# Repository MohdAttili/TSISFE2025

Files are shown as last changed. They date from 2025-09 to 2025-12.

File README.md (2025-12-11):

## WRO-FUTURE-ENGINEERS-2025 - TEAM TUREAH

<p align="center">
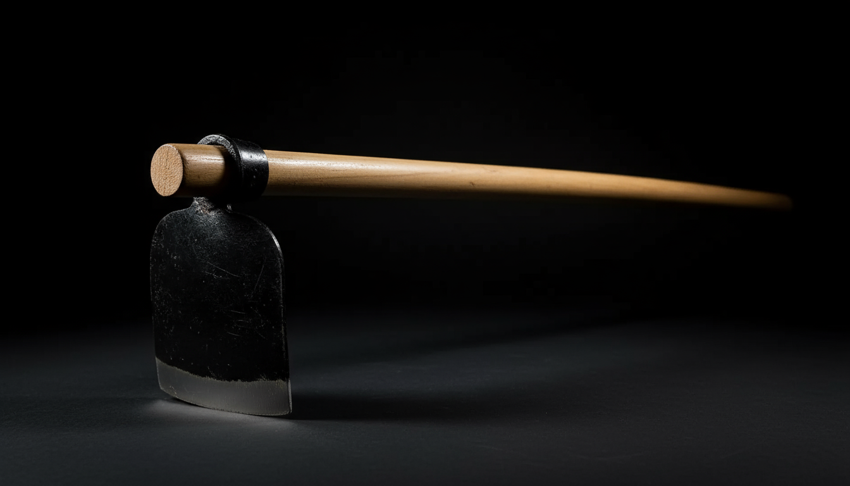
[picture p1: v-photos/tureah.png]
Team Photo

</p>

---

## Vehicle Preview
<p align="center">
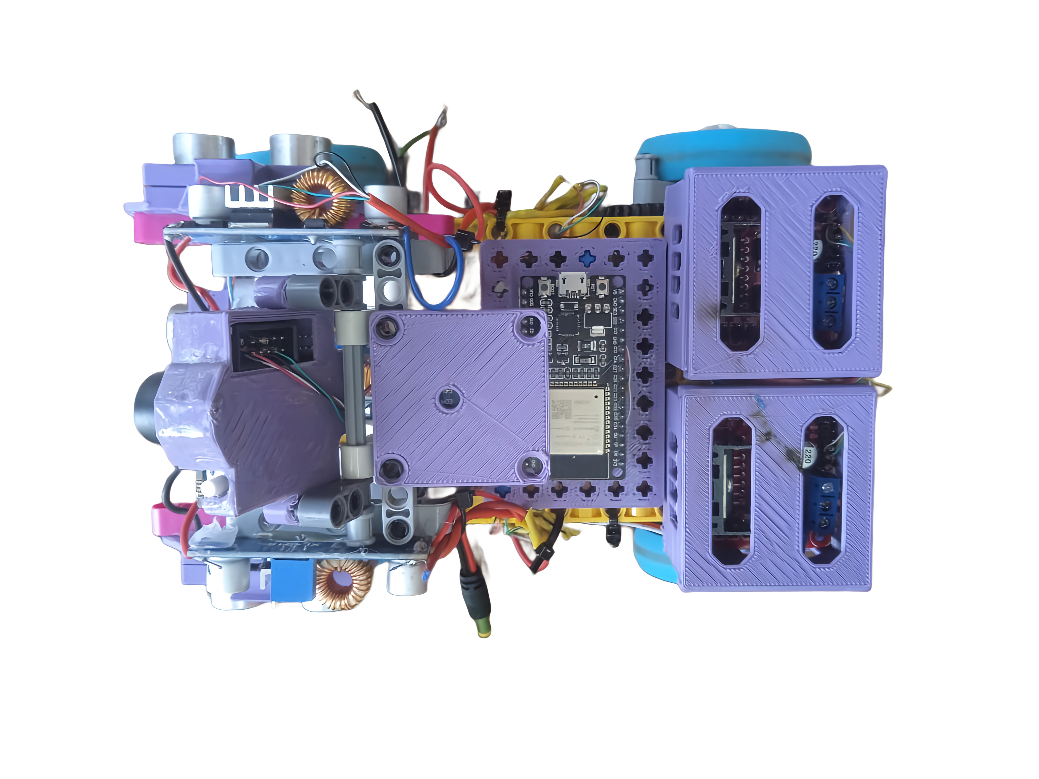
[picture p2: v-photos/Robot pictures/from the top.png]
Vehicle Photo

</p>

---
An autonomous vehicle designed for the Future Engineers category of the WRO 2025 that uses computer vision and IMU sensors to navigate complex environments and avoid obstacles intelligently.

## Content Structure

📁 **t-photos** → [team photos ](https://github.com/MohdAttili/TSISFE2025/tree/main/t-photos)   
📁 **v-photos** → [vehicle photos  ](https://github.com/MohdAttili/TSISFE2025/tree/main/v-photos)   
📁 **video** → [video.md with demonstration link  ](https://github.com/MohdAttili/TSISFE2025/tree/main/video)   
📁 **schemes** → [schematic diagrams ](https://github.com/MohdAttili/TSISFE2025/tree/main/schemes)    
📁 **src** → [control software  ](https://github.com/MohdAttili/TSISFE2025/tree/main/src)   
📁 **models** → [3D printing / laser cutting / CNC files ](https://github.com/MohdAttili/TSISFE2025/tree/main/models)    
📁 **other** → [documentation and additional resources  ](https://github.com/MohdAttili/TSISFE2025/tree/main/other)   
## Project Overview
This repository contains all the engineering materials, code, schematics, and models related to our self-driven vehicle, designed and built to participate in the WRO Future Engineers 2025 competition. The project aims to develop an autonomous vehicle capable of navigating a predefined course while demonstrating precision, stability, and effective control of electromechanical components.

Our vehicle is a compact, versatile model incorporating both mechanical and electronic systems. It is designed to efficiently demonstrate autonomous navigation using sensors, motor control, and a central microcontroller. The design and implementation of this project involved detailed planning, testing, and iterative improvements to meet the strict requirements of the competition.
## -------------------------------------------------------------------------------------
## Why TUREAH

**Our team is called "TUREAH" after the farming tool, symbolizing hard work, perseverance, and the ability to overcome obstacles. Just like the tool prepares the soil for growth, our team paves the way for success. 🌱**
## -------------------------------------------------------------------------------------

## Who We Are

<!-- <p align="center">
<img src="t-photos/karem1.jpg" alt="Kareem" width="240"height="250" />
<img src="t-photos/attili.jpg" alt="Attili" width="240"/>
<img src="t-photos/osama1.jpeg" alt="Osama" width=240/>
</p> -->

<table border="1">
  <tr>
    <td align="center">
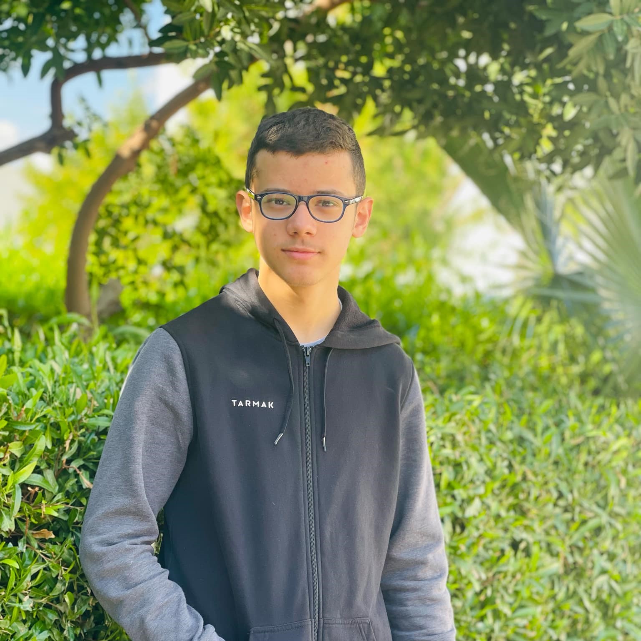
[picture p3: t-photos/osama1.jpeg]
      <br>
      Osama Jadbah<br>
      Planning <br>
      Research<br>
      Documentation
    </td>
    <td align="center">
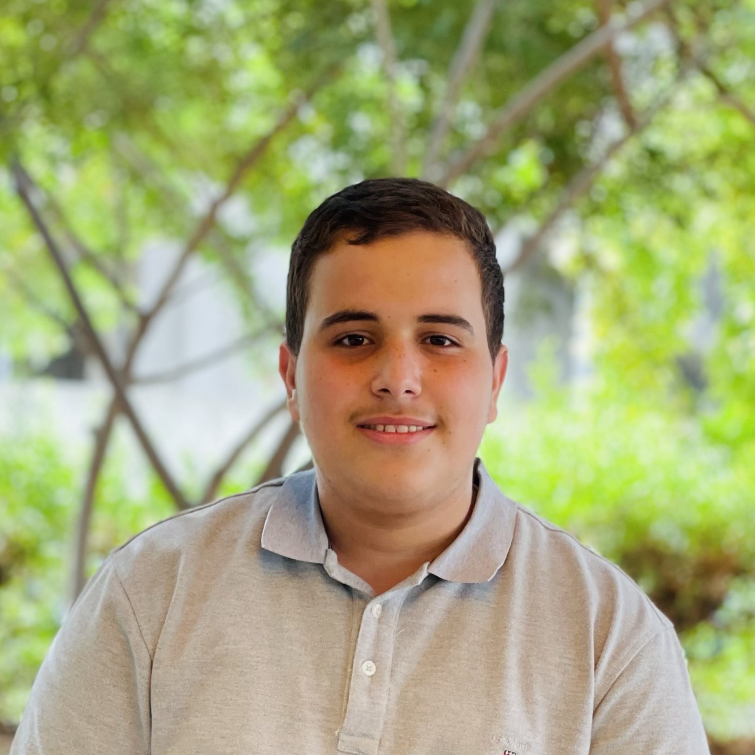
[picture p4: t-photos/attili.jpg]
      <br>
      Mohammad Attili<br>
      Hardware <br>
      Software
    </td>
    <td align="center">
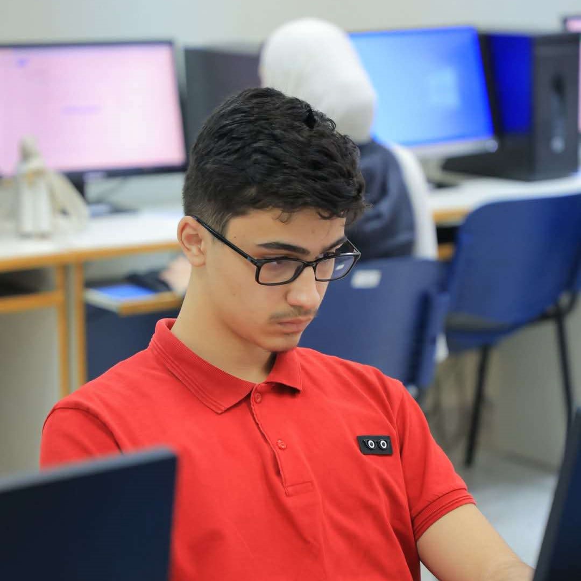
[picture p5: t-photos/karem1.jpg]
      <br>
      Kareem Amr<br>
      Mechanical Design<br>
      Algorithms
    </td>    
  </tr>
</table>

We are a team of three passionate Palestinian students from Tulkarm Industrial Secondary School, united by our love for programming, artificial intelligence, and problem-solving. Osama Jadbah, an 11th-grade student, focuses on lifelong learning, self-development, and has earned multiple excellence certificates for his achievements. Mohammad Attili, 16, is a competitive programmer who has excelled in national and international contests, showcasing his innovation and tech skills. Kareem Amr, also 16, is a skilled programmer and problem solver, experienced in algorithms and competitive programming, and an accomplished chess player who earned 3rd place in the Palestinian Chess Championship. Together, we strive to develop our skills, tackle challenging projects, and explore new technological horizons.
[Further Information](https://github.com/MohdAttili/TSISFE2025/blob/main/t-photos/Team%20Description.pdf)
## -------------------------------------------------------------------------------------
## 🔍 Project Description
**🎯 Goals**  
1. Build a functional self-driven vehicle that can navigate a course autonomously.  
2. Integrate electronic and mechanical components seamlessly.  
3. Develop modular and maintainable code to control all vehicle components.  
4. Document all aspects of the vehicle's design, construction, and programming.  
5. Provide clear and detailed engineering materials to facilitate understanding and replication.  

 ## ⚙️ Physical Equipment  
**1. 🧠 ESP32-WROOM-32 Overview**
1. ESP32-WROOM-32 is a microcontroller by Espressif with Wi-Fi and Bluetooth, commonly used in smart devices and robotics.
2. It features a dual-core Xtensa 32-bit LX6 processor up to 240 MHz, with 520 KB SRAM and 4 MB Flash.
3. Offers around 34 programmable GPIO pins and interfaces like SPI, I2C,  UART, PWM, and I2S, with ADC/DAC support.  
4. Supports dual connectivity, multiple protocols, and has a large  community with ready-to-use libraries.  
5. Common applications include robotics, smart home systems, remote   measurement/control devices, and IoT data collection.  
                    
**2. 🤖 L298N (Motor Driver Module) Overview**
1. The L298N is a dual H-bridge motor driver used to control the speed and direction of DC and stepper motors.
2. Supports motor voltages from 5V to 35V and currents up to 2A per channel.
3. Motor direction is controlled via IN1–IN4 pins and speed via PWM (ENA/ENB pins).
4. Features include independent dual motor control, built-in heat sink, and easy interfacing with Arduino, ESP32, and Raspberry Pi.
5. Commonly used in robotics, motorized DIY projects, and stepper motor control for small CNC machines or 3D printers.

**3. 📏 HC-SR04 Ultrasonic Sensor Overview**     
1. Ultrasonic distance sensor used to measure distances to objects.
2. Sends ultrasonic waves and calculates the time for echo return.
3. Affordable, simple, and widely used in robotics and obstacle detection.
4. Features a simple 4-pin interface: VCC, GND, TRIG, ECHO.
5. Provides accurate distance measurement (2 cm – 400 cm, ±3 mm).
     
**4.🎥 Pixy 2.1 (CMUcam5) Overview**
1. The Pixy 2.1 is a smart vision sensor that detects and tracks objects by color or shape.
2. Resolution: 320×200 pixels, frame rate up to 60 fps, with interfaces SPI, I²C, UART, and USB.
3. Built-in processor allows real-time object recognition and can track multiple objects simultaneously.
4. Sends object coordinates directly to microcontrollers like Arduino or ESP32, reducing main board load.
5. Common applications include line-following robots, object detection/sorting, interactive projects, and educational AI experiments.

**5. 🚗 LEGO Wheel Ø56 with Medium Azure Tire Overview**
1. LEGO Technic wheel with a 56 mm diameter and medium azure rubber tire.
2. Part numbers: 39367 (wheel) and 1282073 (tire).
3. Designed for medium-sized LEGO vehicles and robots.
4. Durable and easy to fit with LEGO axles, providing reliable traction.
5. Common uses: LEGO Mindstorms robots, Spike Prime projects, and DIY educational builds.

**6. ⚡ MG996R Servo Overview**
1. High-torque digital servo with reliable performance and precise positioning.   
2. Operating Voltage: 4.8–6.0V DC, providing ~9.4–11 kg·cm torque.     
3. Applications: Suitable for steering, robotic arms, and hobby projects.   
4. Motor & Gears: Coreless motor with durable metal gears for smooth, accurate motion.   
4. Control & Integration: Controlled via standard PWM; compatible with Arduino, Raspberry Pi, and robotics kits.   

**7. ⚙️ EV3 Medium Motor Overview**
1. A LEGO Mindstorms motor designed for precise and controlled movement.
2. Operates at ~255 RPM with medium torque, ideal for steering mechanisms.
3. Features a built-in rotation sensor for accurate position feedback.
4. Supports precise angle control (servo-like behavior) and smooth acceleration.
5. Commonly used in LEGO Technic robots for steering and articulated parts.
      
**8. 🧩 EV3 LEGO Technic Set Pieces Overview**
1. Modular LEGO Technic parts used to build robots, vehicles, and mechanical systems.
2. Include beams, liftarms, axles, connectors, gears, pulleys, pins, and bushings.
3. Provide the structural framework and enable integration of motors, sensors, and controllers.
4. Designed for reusability and compatibility with LEGO EV3 robotics kits.
5. Commonly used for creating chassis, motion systems, and custom robotic designs.    

[More Details about the Components](https://github.com/MohdAttili/TSISFE2025/blob/main/other/Selected%20Components.pdf)

[Comparisons with Other Components in the Market](https://github.com/MohdAttili/TSISFE2025/blob/main/other/Comparison%20with%20Other%20Components.pdf) 
 <p align="center">
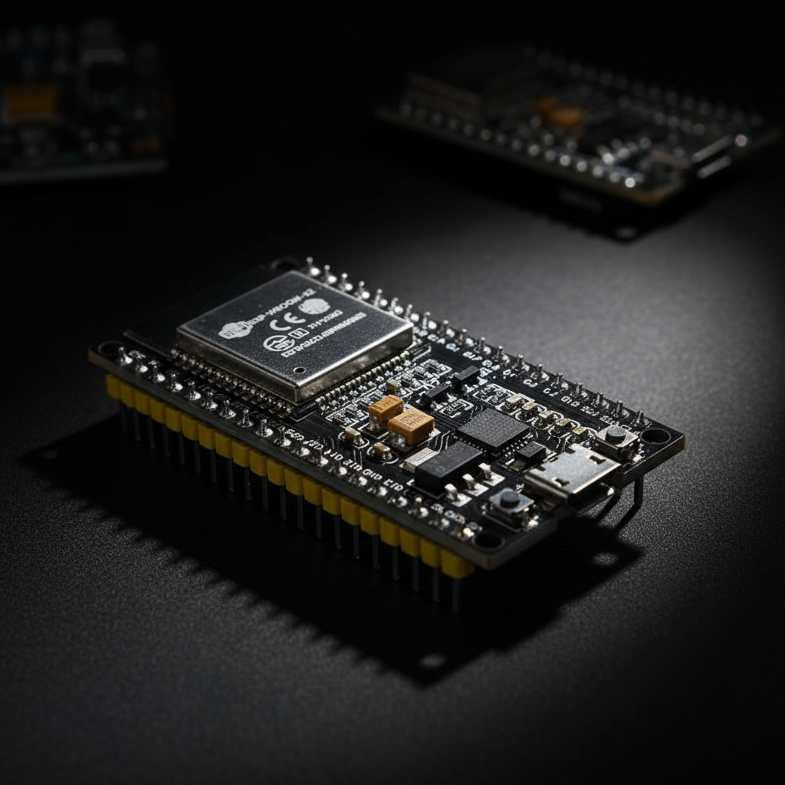
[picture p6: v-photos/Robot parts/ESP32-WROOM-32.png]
  
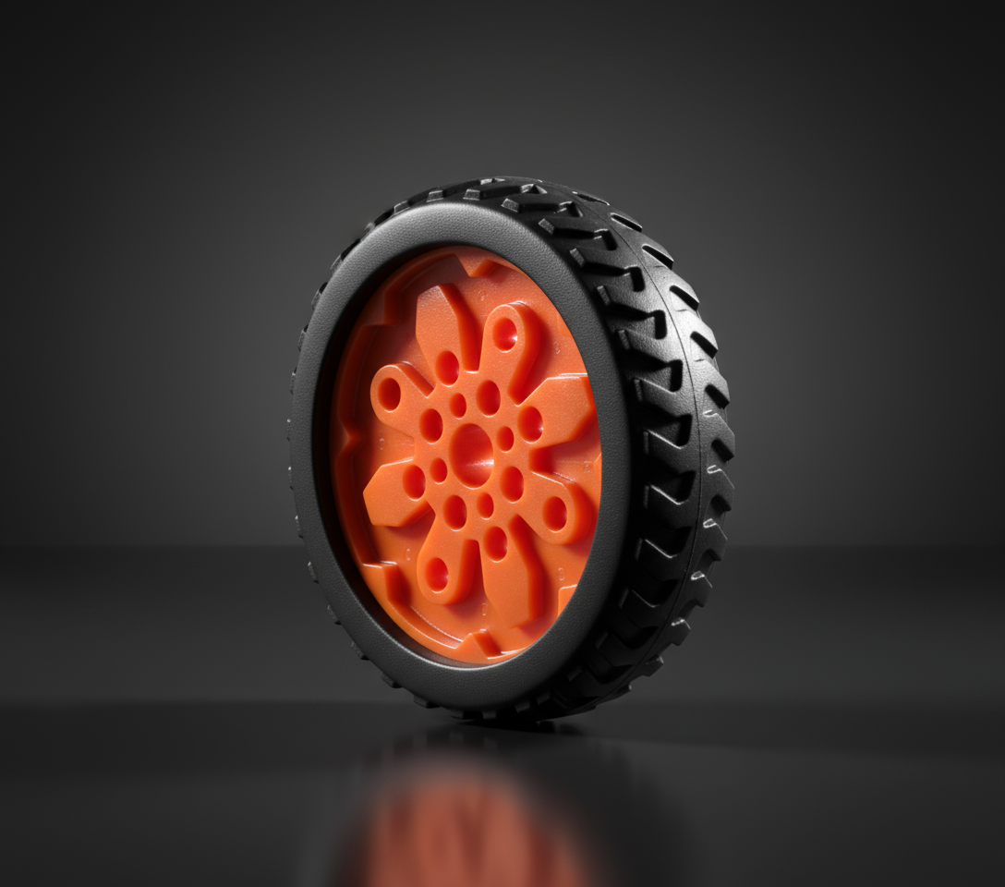
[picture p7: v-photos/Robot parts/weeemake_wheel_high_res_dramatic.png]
  
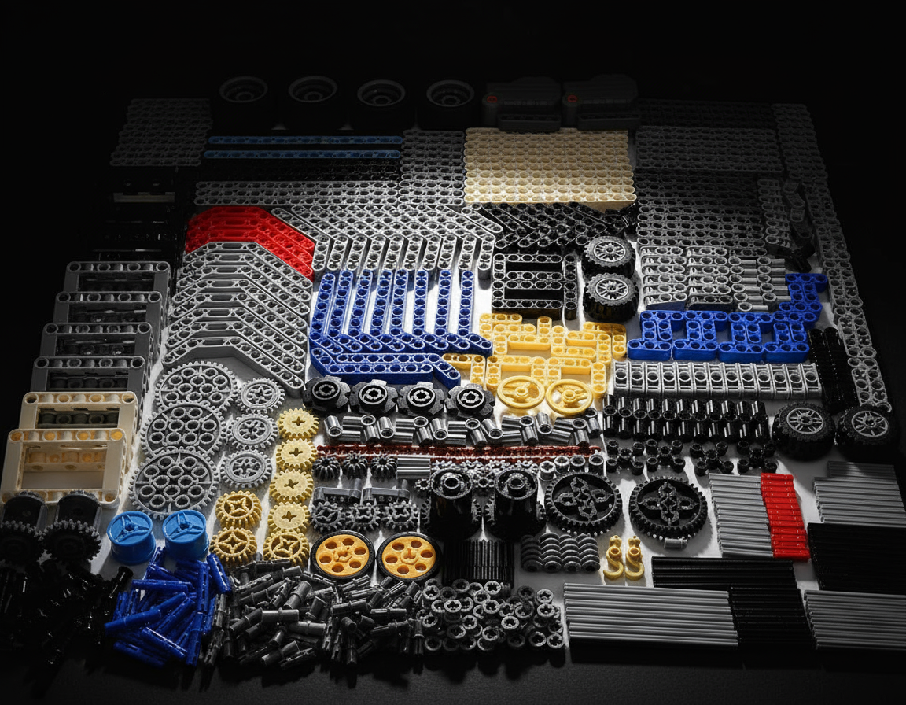
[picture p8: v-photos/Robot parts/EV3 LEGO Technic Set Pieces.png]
  
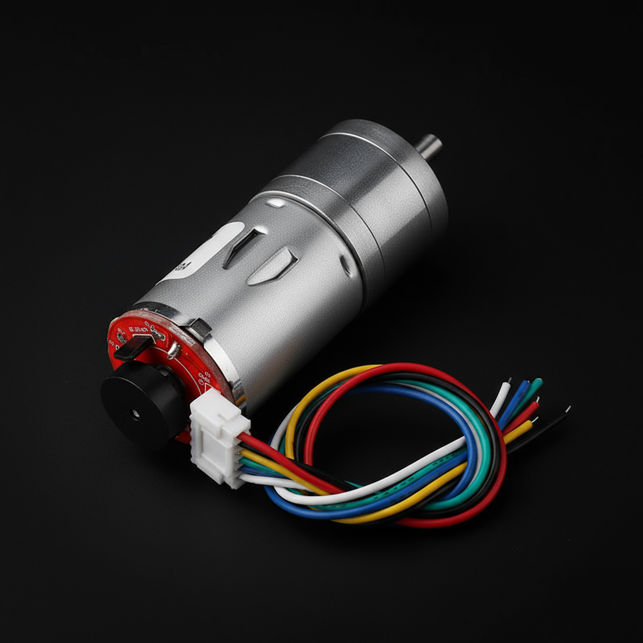
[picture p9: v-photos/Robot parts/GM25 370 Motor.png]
  
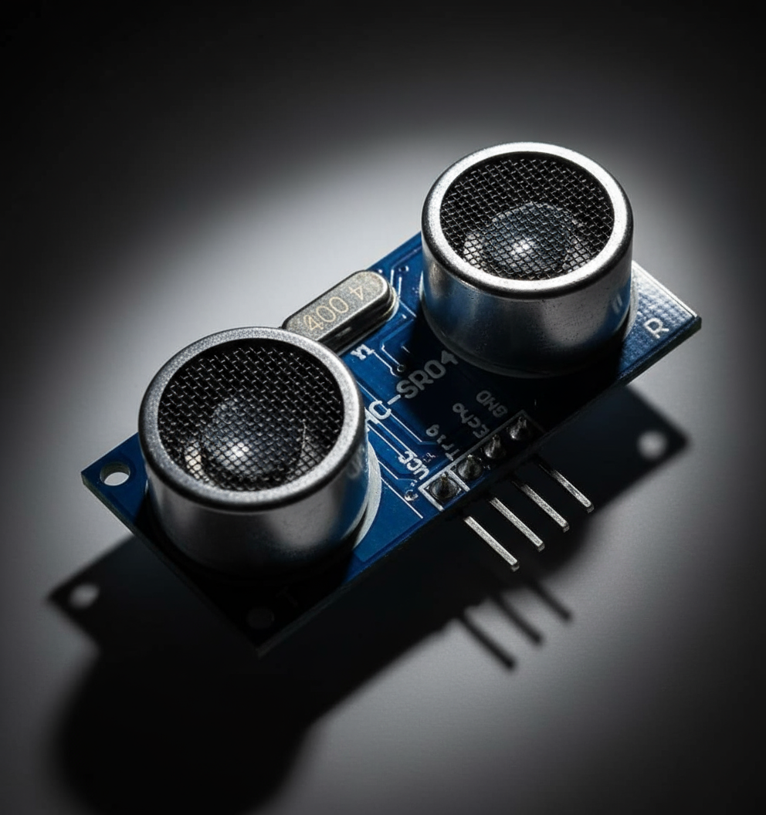
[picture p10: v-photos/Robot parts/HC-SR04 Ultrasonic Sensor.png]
  
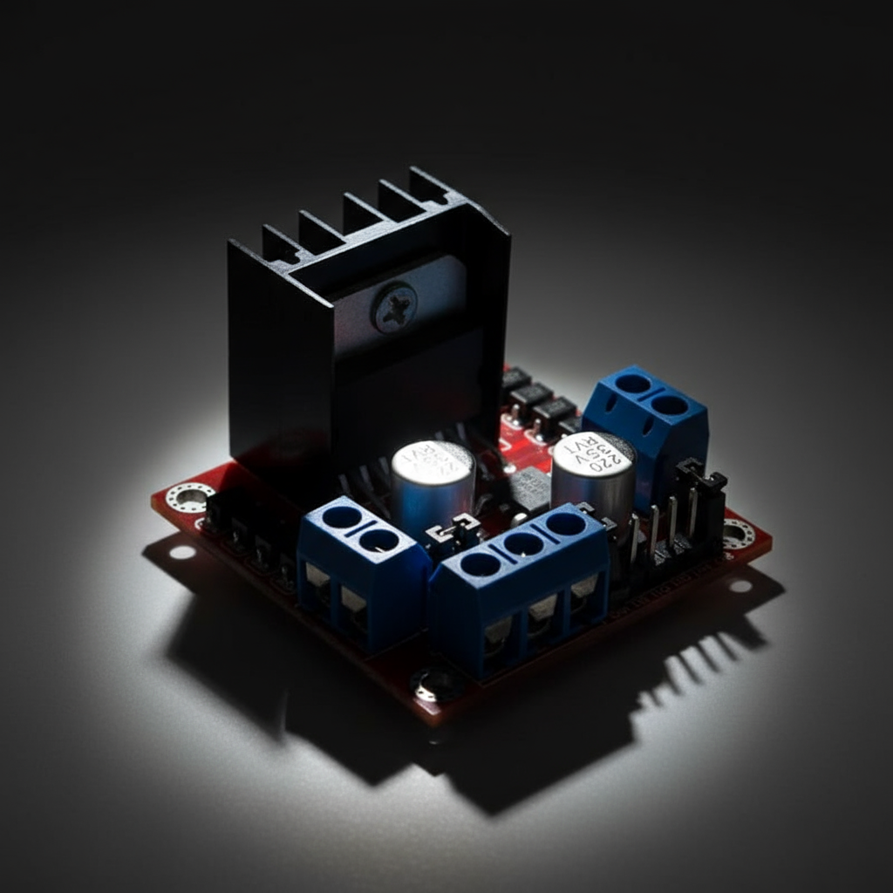
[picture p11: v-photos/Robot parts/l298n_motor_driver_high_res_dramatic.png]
  
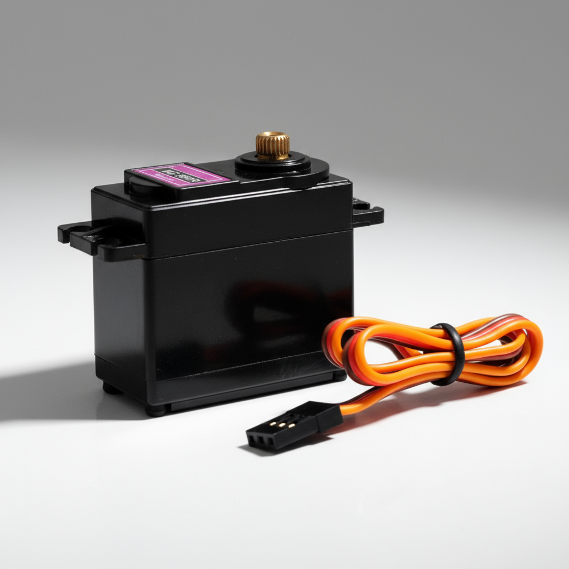
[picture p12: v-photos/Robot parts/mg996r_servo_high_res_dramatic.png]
  
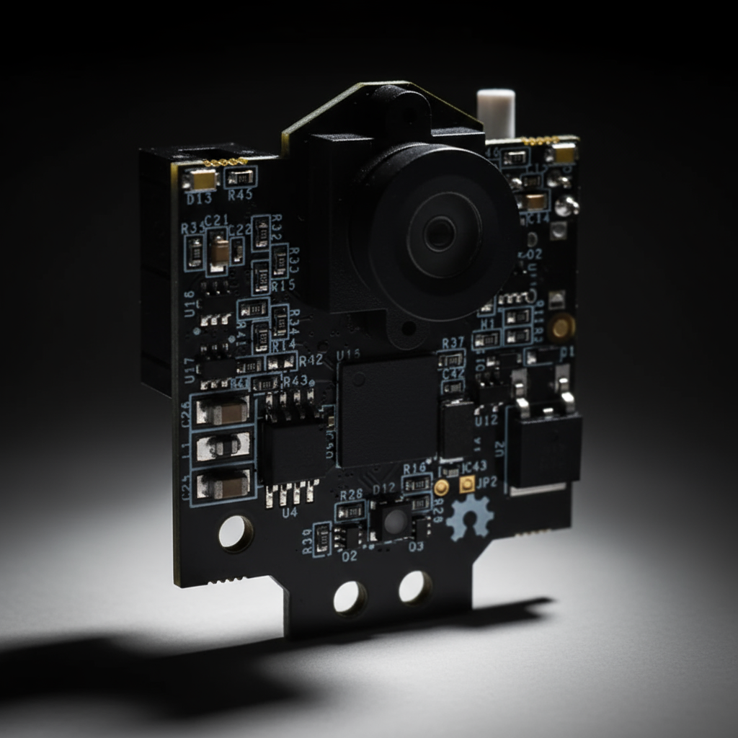
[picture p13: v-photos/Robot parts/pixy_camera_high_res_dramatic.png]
  
</p>
Esp32 wroom 32-d *1
 ESP Shield *1 
TOF 200C *1 
TOF 400c *3 
Xh Connectors 
4.3’ oled display  *2
 Jga52-370 12V Motor *1
 Mg996R Servo *1 
AUG 22 Wires
 L298N Motor Driver *1
 Metal Gear set 
M3 Screws
 M4 screws 
Pixy2 cam *1 
MPU6050 Gyroscope*1
## -------------------------------------------------------------------------------------
## 🎮 The Code 
**Cam Test Code**
```cpp
#include <Pixy2I2C.h>
#include <Wire.h>

Pixy2I2C cam;

void setup() {
Serial.begin(115200);
Wire.begin(21, 22); 
cam.init();
delay(500);
}
```
<details>
<summary>Show remaining code</summary>

```cpp
    char getObstcaleColor(){
    cam.ccc.getBlocks();
    int numBlocks = cam.ccc.numBlocks;
    if (numBlocks > 0) {
        int largestIndex = 0;
        int maxArea = 0;

        for (int i = 0; i < numBlocks; i++) {
        int area = cam.ccc.blocks[i].m_width * cam.ccc.blocks[i].m_height;
        if (area > maxArea) {
            maxArea = area;
            largestIndex = i;
        }
        }
        
        int obstcaleColor =cam.ccc.blocks[largestIndex].m_signature;
        
        if(obstcaleColor == 1||obstcaleColor == 2||obstcaleColor == 3||obstcaleColor == 4){
        return 'R';
        }
        else if (obstcaleColor == 5||obstcaleColor == 6||obstcaleColor == 7||obstcaleColor == 8){
        return 'G';
        }
        else{
        return 'U';
        }
    }
    else{
        return 'N';
        }
    }
    void loop() {

    Serial.println(getObstcaleColor());
    delay(200);

    }
```
</details>

## --------------------------------------------------------------------------------------
**Ultrasonic Sensor Code**

```cpp

    // Ultrasonic Sensor Pins
    const int TRIG1 = 27;
    const int ECHO1 = 14;

    const int TRIG2 = 12;
    const int ECHO2 = 13;

    const int TRIG3 = 2;
    const int ECHO3 = 15;

    // Sensor names
    String sensorNames[] = {"Sensor 1", "Sensor 2", "Sensor 3"};

    void setup() {
    Serial.begin(115200);
 ```   
<details>
<summary>Show remaining code</summary>

```cpp
    // Ultrasonic Sensor Pins
    const int TRIG1 = 27;
    const int ECHO1 = 14;

    const int TRIG2 = 12;
    const int ECHO2 = 13;

    const int TRIG3 = 2;
    const int ECHO3 = 15;

    // Sensor names
    String sensorNames[] = {"Sensor 1", "Sensor 2", "Sensor 3"};

    void setup() {
    Serial.begin(115200);

    // Initialize trigger pins as outputs
    pinMode(TRIG1, OUTPUT);
    pinMode(TRIG2, OUTPUT);
    pinMode(TRIG3, OUTPUT);
    
    // Initialize echo pins as inputs
    pinMode(ECHO1, INPUT);
    pinMode(ECHO2, INPUT);
    pinMode(ECHO3, INPUT);
    
    // Ensure triggers are low
    digitalWrite(TRIG1, LOW);
    digitalWrite(TRIG2, LOW);
    digitalWrite(TRIG3, LOW);
    
    Serial.println("ESP32 Ultrasonic Sensor Test");
    Serial.println("=============================");
    delay(100);
    }

    long getDistance(int trigPin, int echoPin) {
    digitalWrite(trigPin, LOW);
    delayMicroseconds(2);
    
    // Send 10 microsecond pulse
    digitalWrite(trigPin, HIGH);
    delayMicroseconds(10);
    digitalWrite(trigPin, LOW);
    
    // Read the echo pulse duration
    long duration = pulseIn(echoPin, HIGH, 30000); // 30ms timeout (~5m range)
    
    // Calculate distance in cm
    long distance = duration * 0.034 / 2;
    
    return distance;
    }

    void testAllSensors() {
    Serial.println("\nTesting all sensors...");
    Serial.println("---------------------");
    
    // Test Sensor 1
    long dist1 = getDistance(TRIG1, ECHO1);
    Serial.print(sensorNames[0] + ": ");
    if (dist1 > 0 && dist1 < 400) {
        Serial.print(dist1);
        Serial.println(" cm");
    } else {
        Serial.println("Out of range");
    }
    
    // Test Sensor 2
    long dist2 = getDistance(TRIG2, ECHO2);
    Serial.print(sensorNames[1] + ": ");
    if (dist2 > 0 && dist2 < 400) {
        Serial.print(dist2);
        Serial.println(" cm");
    } else {
        Serial.println("Out of range");
    }
  
```
</details>

## --------------------------------------------------------------------------------------

**Motor Testing Code**
```cpp
// Motor Control Pins
#define ENA 16    // PWM pin for speed control
#define IN1 17    // Direction control 1
#define IN2 5     // Direction control 2

// Encoder Pins
#define ENC_A 32  // Encoder channel A
#define ENC_B 33  // Encoder channel B

// Variables for encoder counting
volatile long encoderCount = 0;
int lastEncA = 0;
int lastEncB = 0;

// Motor control parameters
int motorSpeed = 200;  // PWM value (0-255)
bool motorDirection = true; // true = forward, false = reverse

 ```   
<details>
<summary>Show remaining code</summary>

```cpp

void setup() {
  // Initialize serial communication
  Serial.begin(115200);
  
  // Set motor control pins as outputs
  pinMode(ENA, OUTPUT);
  pinMode(IN1, OUTPUT);
  pinMode(IN2, OUTPUT);
  
  // Set encoder pins as inputs with pullup resistors
  pinMode(ENC_A, INPUT_PULLUP);
  pinMode(ENC_B, INPUT_PULLUP);
  
  // Read initial encoder state
  lastEncA = digitalRead(ENC_A);
  lastEncB = digitalRead(ENC_B);
  
  // Attach interrupt for encoder pin A
  attachInterrupt(digitalPinToInterrupt(ENC_A), updateEncoder, CHANGE);
  
  Serial.println("ESP32 Motor Control with Encoder");
  Serial.println("Commands: ");
  Serial.println("  F - Forward");
  Serial.println("  R - Reverse");
  Serial.println("  S - Stop");
  Serial.println("  + - Increase Speed");
  Serial.println("  - - Decrease Speed");
  Serial.println("  P - Print encoder count");
}

void loop() {
  // Check for serial commands
  if (Serial.available()) {
    char command = Serial.read();
    
    switch(command) {
      case 'F':
      case 'f':
        motorForward();
        Serial.println("Motor: FORWARD");
        break;
        
      case 'R':
      case 'r':
        motorReverse();
        Serial.println("Motor: REVERSE");
        break;
        
      case 'S':
      case 's':
        motorStop();
        Serial.println("Motor: STOP");
        break;
        
      case '+':
        increaseSpeed();
        Serial.print("Speed increased to: ");
        Serial.println(motorSpeed);
        break;
        
      case '-':
        decreaseSpeed();
        Serial.print("Speed decreased to: ");
        Serial.println(motorSpeed);
        break;
        
      case 'P':
      case 'p':
        Serial.print("Encoder pulses: ");
        Serial.println(encoderCount);
        break;
    }
  }
  
  // Small delay to prevent overwhelming the serial
  delay(100);
}

// Encoder interrupt service routine
void updateEncoder() {
  int currentEncA = digitalRead(ENC_A);
  int currentEncB = digitalRead(ENC_B);
  
  // Determine direction based on state changes
  if (currentEncA != lastEncA) {
    if (currentEncA == currentEncB) {
      encoderCount++;
    } else {
      encoderCount--;
    }
  } else if (currentEncB != lastEncB) {
    if (currentEncA == currentEncB) {
      encoderCount--;
    } else {
      encoderCount++;
    }
  }
  
  lastEncA = currentEncA;
  lastEncB = currentEncB;
}

// Motor control functions
void motorForward() {
  digitalWrite(IN1, HIGH);
  digitalWrite(IN2, LOW);
  analogWrite(ENA, motorSpeed);
  motorDirection = true;
}

void motorReverse() {
  digitalWrite(IN1, LOW);
  digitalWrite(IN2, HIGH);
  analogWrite(ENA, motorSpeed);
  motorDirection = false;
}

void motorStop() {
  digitalWrite(IN1, LOW);
  digitalWrite(IN2, LOW);
  analogWrite(ENA, 0);
}

void increaseSpeed() {
  motorSpeed = min(255, motorSpeed + 25);
  analogWrite(ENA, motorSpeed);
}

void decreaseSpeed() {
  motorSpeed = max(0, motorSpeed - 25);
  analogWrite(ENA, motorSpeed);
}

```
</details>

## --------------------------------------------------------------------------------------

**open challenge v1.0**
```cpp
#include <ESP32Servo.h>
#include <Arduino.h>
#include <Wire.h>
#include <NewPing.h>

// ==================== Hardware ====================
Servo myservo;
const int servoPin = 32;

#define US_LEFT_TRIG 27
#define US_LEFT_ECHO 14
#define US_FRONT_TRIG 12
#define US_FRONT_ECHO 13
#define US_RIGHT_TRIG 2
#define US_RIGHT_ECHO 15
#define MAX_DISTANCE 200

NewPing sonar_left(US_LEFT_TRIG, US_LEFT_ECHO, MAX_DISTANCE);
NewPing sonar_front(US_FRONT_TRIG, US_FRONT_ECHO, MAX_DISTANCE);
NewPing sonar_right(US_RIGHT_TRIG, US_RIGHT_ECHO, MAX_DISTANCE);

#define MOTOR1_IN1 17
#define MOTOR1_IN2 5
#define MOTOR1_ENA 16

const int MOTOR1_CHANNEL = 1; // Motor channel
const int SERVO_CHANNEL = 0;  // Servo channel

#define MAX_STEERING_ANGLE 20   // ±20°

 ```   
<details>
<summary>Show remaining code</summary>

```cpp

// MPU6050 Address
const int MPU_addr = 0x68;

// Gyroscope calibration and yaw tracking
float gyroX_bias = 0;
float gyroY_bias = 0;
float gyroZ_bias = 0;
float yaw = 0;
unsigned long prevTime = 0;

// ---------------- MPU Functions ----------------
int16_t read16(int addr) {
  int16_t value;
  Wire.beginTransmission((uint8_t)MPU_addr);
  Wire.write((uint8_t)addr);
  Wire.endTransmission(false);
  Wire.requestFrom((uint16_t)MPU_addr, (uint8_t)2, (uint8_t)true);
  value = (Wire.read() << 8) | Wire.read();
  return value;
}

void calibrateGyro(int samples = 200) {
  long sumX = 0, sumY = 0, sumZ = 0;
  for (int i = 0; i < samples; i++) {
    int16_t gx = read16(0x43);
    int16_t gy = read16(0x45);
    int16_t gz = read16(0x47);
    sumX += gx; sumY += gy; sumZ += gz;
    delay(5);
  }
  gyroX_bias = sumX / (float)samples;
  gyroY_bias = sumY / (float)samples;
  gyroZ_bias = sumZ / (float)samples;

void resetGyro() {
  yaw = 0;
  prevTime = millis();
}

void setupMPU() {
  Wire.begin();
  Wire.beginTransmission(MPU_addr);
  Wire.write(0x6B);
  Wire.write(0);
  Wire.endTransmission(true);
}

float getYaw() {
  unsigned long currentTime = millis();
  float dt = (currentTime - prevTime) / 1000.0;
  prevTime = currentTime;

  int16_t gz_raw = read16(0x47);
  float gz = gz_raw - gyroZ_bias;
  float gz_dps = gz / 131.0;

  yaw += gz_dps * dt;
  if (yaw > 180) yaw -= 360;
  if (yaw < -180) yaw += 360;

  return yaw;
}

float get_distance(NewPing &sensor) {
    float sum = 0;
    byte valid = 0;
    for (byte i = 0; i < 5; i++) {
        float dist = sensor.ping_cm();
        // Check if the distance is valid (greater than 0 and less than MAX_DISTANCE)
        if (dist > 0 && dist < MAX_DISTANCE) {
            sum += dist;
            valid++;
        }
        // delay(2);  // Small delay between readings
    }
    // If we have valid readings, return the average; otherwise, return MAX_DISTANCE
    return (valid > 0) ? (sum / valid) : MAX_DISTANCE;
}

void setAngle(int angle) {
    myservo.write(angle);  // Move servo to the specified angle
    delay(100);  // Small delay to allow the servo to move
}

void set_drive_motor(int speed) {
    speed = constrain(speed, -1023, 1023);  // Ensure speed is within PWM range
    if (speed >= 0) {
        digitalWrite(MOTOR1_IN1, HIGH);
        digitalWrite(MOTOR1_IN2, LOW);
    } else {
        digitalWrite(MOTOR1_IN1, LOW);
        digitalWrite(MOTOR1_IN2, HIGH);
    }
    ledcWrite(MOTOR1_CHANNEL, abs(speed));  // Motor control using PWM
}

void setup() {
    Serial.begin(115200);
    Wire.begin();
    Wire.setClock(400000);
    delay(500);
    setupMPU();
    delay(500);
    calibrateGyro();
    delay(500);
    resetGyro();
    delay(500);
    pinMode(MOTOR1_IN1, OUTPUT);  // Motor control pins
    pinMode(MOTOR1_IN2, OUTPUT);
    pinMode(MOTOR1_ENA, OUTPUT);

    pinMode(servoPin, OUTPUT);  // Set the servo pin as OUTPUT for PWM

    // Motor PWM setup
    ledcSetup(MOTOR1_CHANNEL, 1000, 10);  // 1000 Hz frequency, 10-bit resolution
    ledcAttachPin(MOTOR1_ENA, MOTOR1_CHANNEL);

    ledcSetup(SERVO_CHANNEL, 50, 16);  // 50Hz for servo control, 16-bit resolution
    ledcAttachPin(servoPin, SERVO_CHANNEL);

    myservo.attach(servoPin, 1000, 2000);  // Attach servo to the pin
    setAngle(113);  // Set initial servo position
}

// ---------------- PID ----------------
float Kp_dist = 0.3, Kd_dist = 1;
float Kp_gyro = 2.0, Kd_gyro = 0.5;

float prev_error_dist = 0;
float prev_error_gyro = 0;

bool use_distance_pid = true;
const float target_yaw = 0.0;

void pid_distance_balance() {
  float left = get_distance(sonar_left);
  float right = get_distance(sonar_right);

  float error = left - right;
  float derivative = error - prev_error_dist;
  prev_error_dist = error;

  float output = (Kp_dist * error) + (Kd_dist * derivative);
  output = constrain(output, -MAX_STEERING_ANGLE, MAX_STEERING_ANGLE);

  if(output>30){
    output=20;
  }
  else if(output<-30){
    output=-20;
  }

  setAngle(113+((int)output*2));

}

unsigned long lastPIDRun = 0;
const unsigned long SENSOR_INTERVAL = 50; // PID interval in ms

int dir=-1;
    int counter = 0;
bool use_pid=false;
void loop() {
  if (counter>11){
    set_drive_motor(0);
    setAngle(113);
    return;
  }
  if (counter>0){
    use_pid=true;
  }
    set_drive_motor(500);
    // Get distance readings from ultrasonic sensors
    float left = get_distance(sonar_left);
    float right = get_distance(sonar_right);
    float front = get_distance(sonar_front);
    if(dir==-1){
            if(right>100){
                dir=1;
            }
            else if(left>100)dir=0;
        }
    
    if (((right>100 && right !=200)||(left>100 && left !=200)) && counter <= 11) {

        if(dir==1){
          counter++;
            resetGyro();
            while(getYaw()>-75){
                    set_drive_motor(500); 

                setAngle(35);  
              }

            resetGyro();
        }
        else if(dir==0){
          counter++;
            resetGyro();
            while(getYaw()<75){
              
                setAngle(180); 
            set_drive_motor(500);
            }
            resetGyro();
        }
      while(right>100||left>100){
        float left = get_distance(sonar_left);
    float right = get_distance(sonar_right);
        setAngle(113);
        set_drive_motor(500);
        if(right+left<120){
          break;
        }
      }
    }
    if(use_pid){
        unsigned long currentMillis = millis();
  if (currentMillis - lastPIDRun >= SENSOR_INTERVAL &&counter<=11) {
    lastPIDRun = currentMillis;
      pid_distance_balance();
    
  }}
}
```
</details>

## Robot Videos  
<table border="1">
  <tr>
    <td align="center">
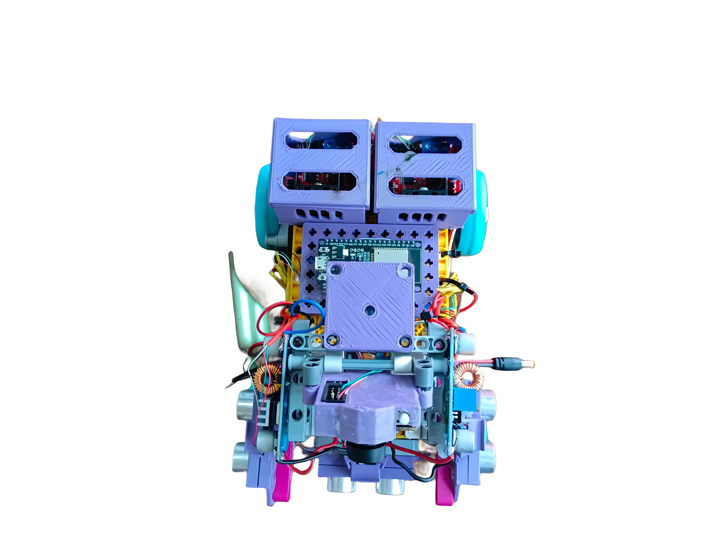
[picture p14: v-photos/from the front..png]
From the right
      <br>  
      <a href="https://youtu.be/vEVCVVJxw5E?si=rrIYacPfhGuDlKN9" target="_blank">Open Challenge</a>
    </td>
    <td align="center">
      From the left<br>
      <a href="Not ready yet" target="_blank">Obstacle Challenge</a>
    </td>  
  </tr>
</table>

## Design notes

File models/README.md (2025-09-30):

## This folder contains a number of 3D models that we printed to fit the pre-prepared chassis. It also includes the components used and a comparison table between them and other components available in the market.

<table>
  <tr>
    <td>
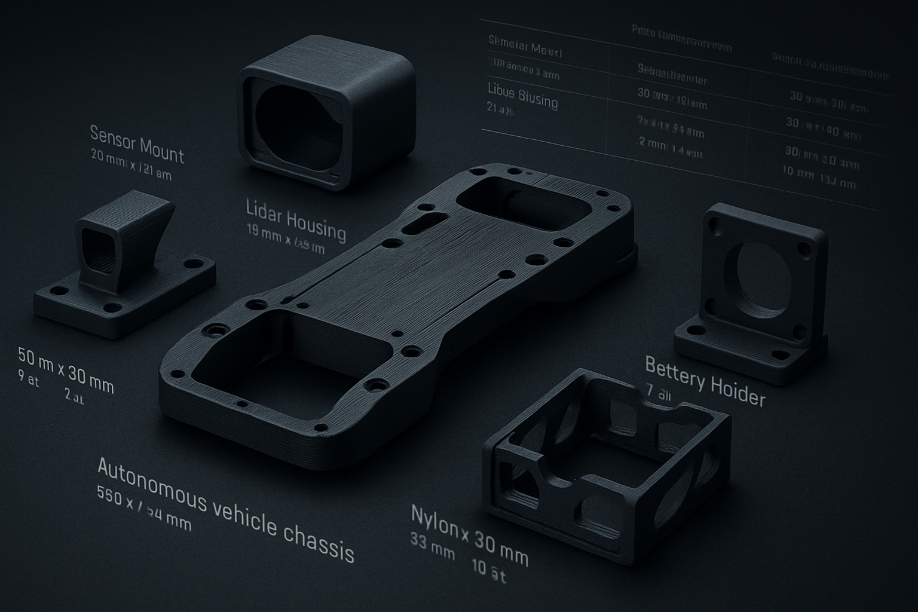
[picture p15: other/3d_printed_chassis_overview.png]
      
    </td>
    <td>
      <p>
        <a href="https://github.com/MohdAttili/TSISFE2025/blob/main/models/Pixy2_Cover.stl">Pixy2_Cover</a><br>
        <a href="https://github.com/MohdAttili/TSISFE2025/blob/main/models/enhanced_holder.stl">enhanced_holder</a><br>
        <a href="https://github.com/MohdAttili/TSISFE2025/blob/main/models/motor%20adapter%20for%20lego.stl">motor adapter for lego</a><br>
        <a href="https://github.com/MohdAttili/TSISFE2025/blob/main/models/Gyroscope%20Holder.stl">Gyroscope Holder</a><br>
        <a href="https://github.com/MohdAttili/TSISFE2025/blob/main/models/Motor%20Driver%20Case.stl">Motor Driver Case</a><br>
        <a href="https://github.com/MohdAttili/TSISFE2025/blob/main/models/Motor%20Driver%20Case%20Cap.stl">Motor Driver Case Cap</a><br>    
        <a href="https://github.com/MohdAttili/TSISFE2025/blob/main/models/Servo%20to%20lego%20adapter.stl">motor adapter for lego</a><br>   
      </p>
    </td>
  </tr>
</table>

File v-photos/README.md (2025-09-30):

## This folder contains vehicle photos and showcases the main components used in the build, such as motors, sensors, wheels, and structural parts. It also includes detailed shots from different angles to document the design process and highlight important features of the robot.

<!-- <p align="center">
<img src="/v-photos/from the right.png" alt="Kareem" width="570" />
</p> -->

<table border="1">
  <tr>
    <td align="center">
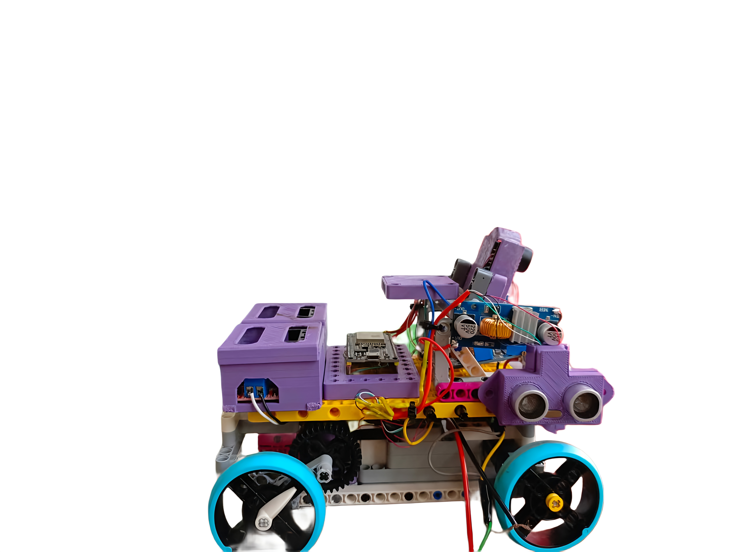
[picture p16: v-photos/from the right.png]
From the right
      <br>
    </td>
    <td align="center">
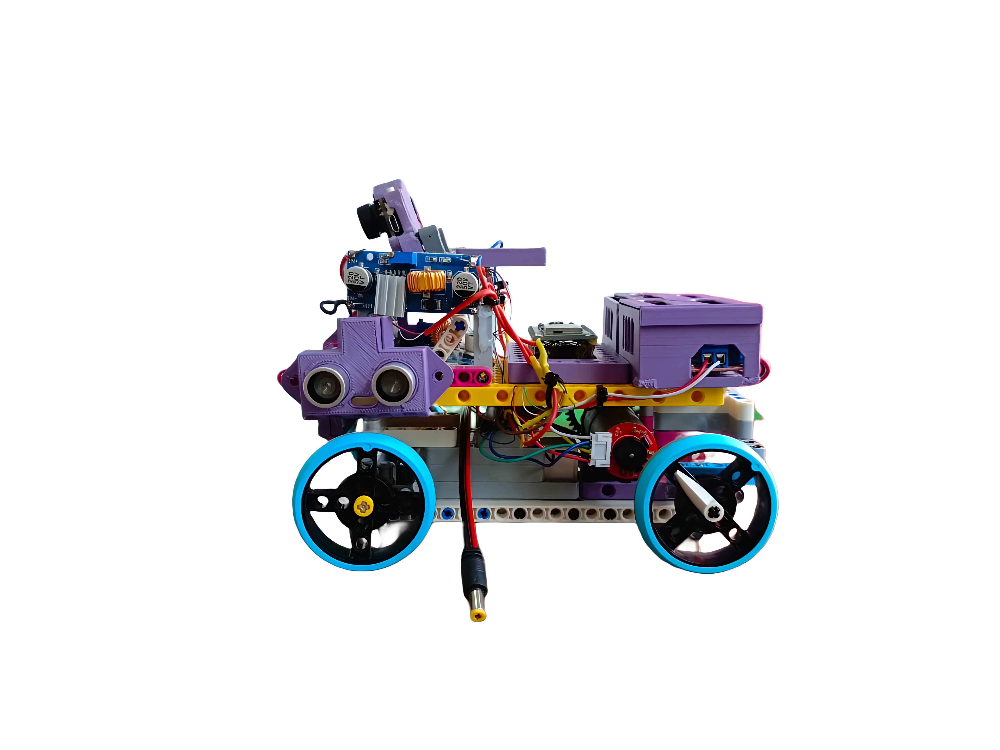
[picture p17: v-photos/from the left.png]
From the left
      <br>
    </td>
  </tr>
</table>

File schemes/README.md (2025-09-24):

## This folder contains schematic diagrams of the vehicle's electromechanical components, including wiring layouts, circuit connections, and mechanical assembly details. These diagrams are provided to document the design and help with troubleshooting or future modifications.

<p align="center">
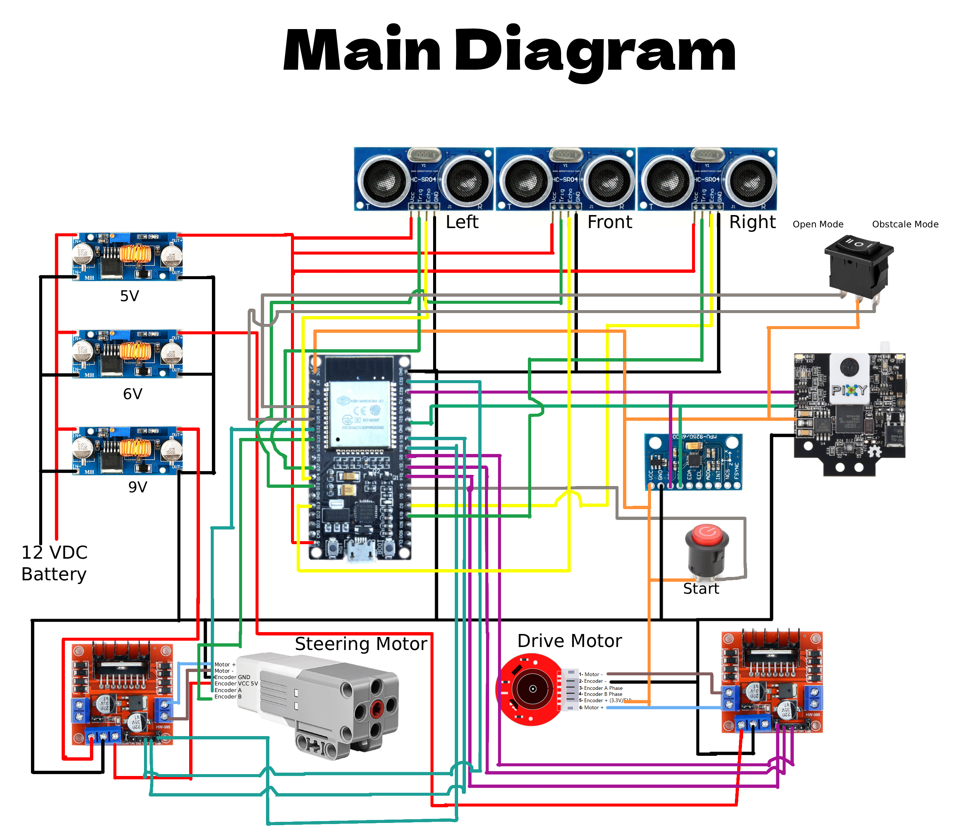
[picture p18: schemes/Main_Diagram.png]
  
</p>

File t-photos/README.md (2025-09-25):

## This folder contains official and casual team photos, including both formal group shots and some fun pictures that capture the team’s spirit.
<!-- 1. [Osama Husam](https://github.com/MohdAttili/TSISFE2025/blob/main/t-photos/%D8%A7%D8%B3%D8%A7%D9%85%D8%A91.jpeg)   
2. [Mohammad Attili](https://github.com/MohdAttili/TSISFE2025/blob/main/t-photos/%D8%B9%D8%AA%D9%8A%D9%84%D9%8A.jpg)   
3. [Kareem Amr](https://github.com/MohdAttili/TSISFE2025/blob/main/t-photos/%D9%83%D8%B1%D9%8A%D9%852.jpg) -->
<table>
  <tr>
    <td>
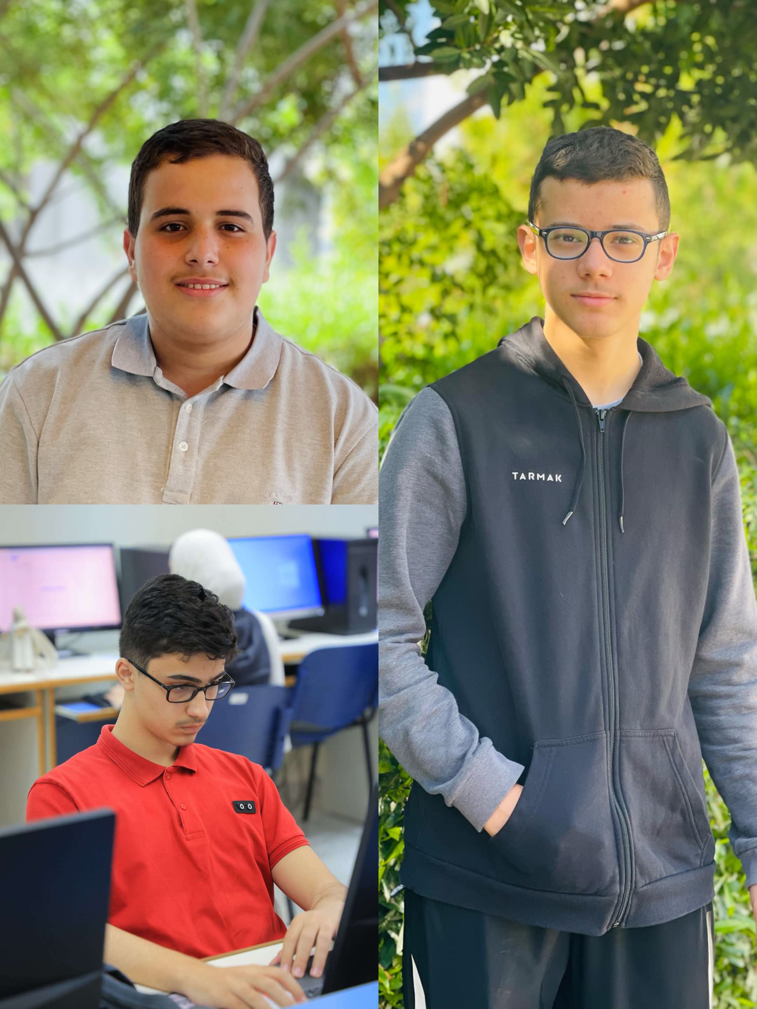
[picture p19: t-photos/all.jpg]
      
    </td>
    <td>
      <p>
        <a href="https://github.com/MohdAttili/TSISFE2025/blob/main/t-photos/Team%20Description.pdf">Team Description</a><br>
        <a href="https://github.com/MohdAttili/TSISFE2025/blob/main/t-photos/karem1.jpg">Kareem Amr</a><br>
        <a href="https://github.com/MohdAttili/TSISFE2025/blob/main/t-photos/osama1.jpeg">Osama Husam</a><br>
        <a href="https://github.com/MohdAttili/TSISFE2025/blob/main/t-photos/attili.jpg">Mohammad Attili</a><br>
</p>
    </td>
  </tr>
</table>

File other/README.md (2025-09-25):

## This folder contains other documentation, datasets, hardware specs, or communication protocols.
<table>
  <tr>
    <td>
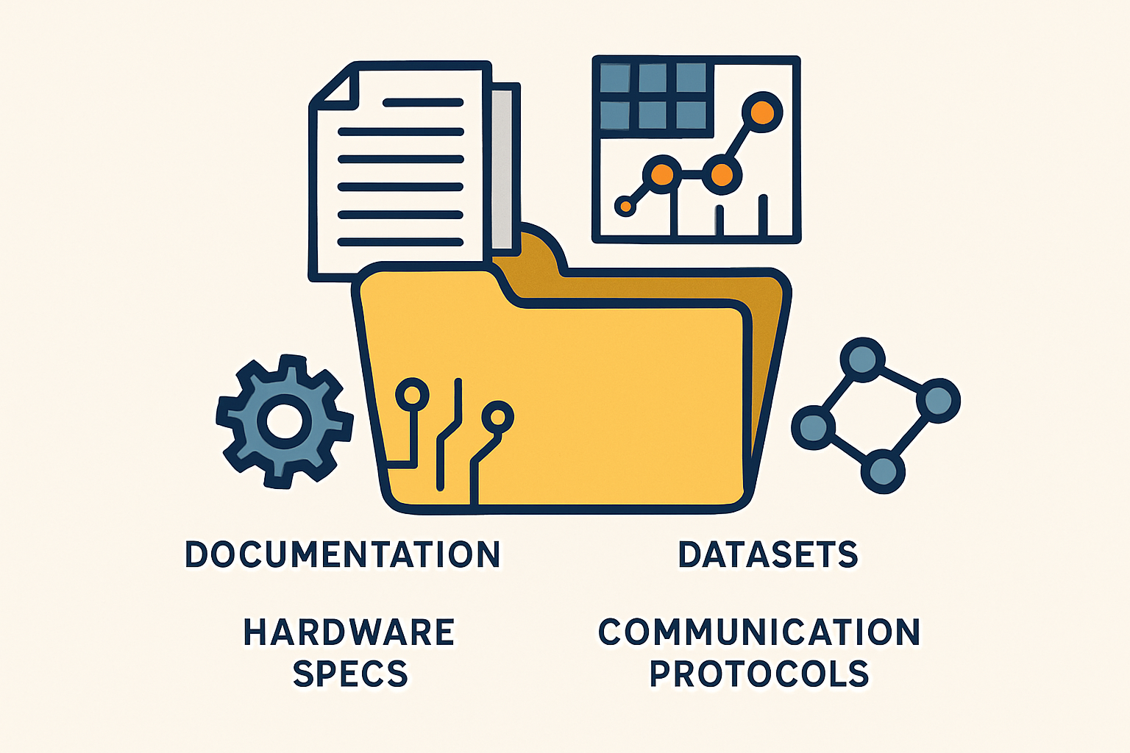
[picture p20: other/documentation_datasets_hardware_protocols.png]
      
    </td>
    <td>
      <p>
        <a href="https://github.com/MohdAttili/TSISFE2025/blob/main/other/Comparison%20with%20Other%20Components.pdf">Comparisons with Other Components in the Market</a><br>
        <a href="https://github.com/MohdAttili/TSISFE2025/blob/main/other/Selected%20Components.pdf">More Details about the Componentsl</a><br>
      </p>
    </td>
  </tr>
</table>

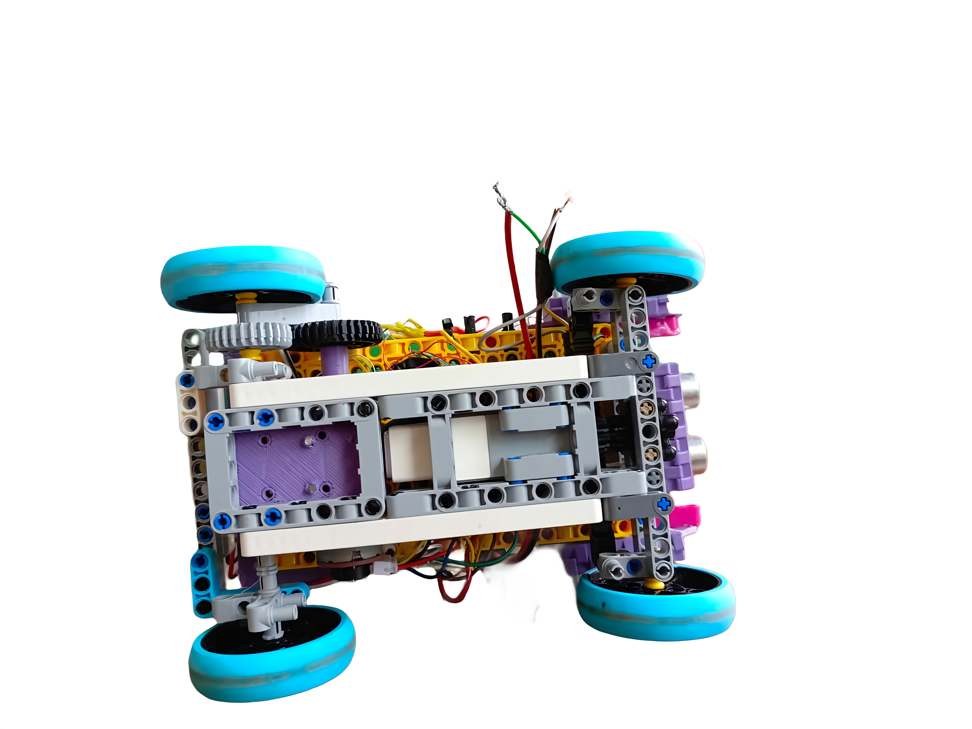
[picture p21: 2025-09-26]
v-photos/Robot pictures/from the bottom.png

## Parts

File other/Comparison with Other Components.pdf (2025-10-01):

Selected Component | Alternative | Comparison | Reason for Preference
ESP-WROOM-32 (Microcontroller) | Arduino Uno / Raspberry Pi Pico | ESP32 is faster (240MHz vs 16MHz for Arduino), built-in Wi-Fi & Bluetooth, lower power consumption. | Ideal for smart robots (wireless control + vision processing + cost-effective).
GM25 370 Motor (Driving Motor) | N20 Gear Motor / DC 775 | Medium size, good torque, suitable speed for small robots, lower power consumption than 775. | Balanced torque, size, and price; compatible with LEGO wheels.
MG996R Servo | High-torque Servo / Digital Servo Motor | MG996R servo is compatible with Arduino and robotics kits, metal gears, stable performance. | Durable, strong torque + easy mounting on standard servo horns.
L298N Motor Driver | L293D / BTS7960 | L298N handles up to 2A, easy to use with ready libraries, cheap and widely available. | Enough for GM25 370 motors, simple wiring, no extra complexity.
Pixy2 Camera (Object Tracking) | OpenMV Cam / Arducam | Pixy2 has built-in color & shape tracking in hardware (no external processing needed), faster response. | Reduces ESP32 load, perfect for small robotics projects.
Ultrasonic HC-SR04 | VL53L0X (ToF Distance Sensor) | Ultrasonic has longer range, easier use, and more available than VL53L0X. | Affordable, easy to integrate, and best suited for obstacle detection in mobile robots.
MPU6050 (Gyro + Accelerometer) | BNO055 / MPU9250 | MPU6050 is cheaper, widely available, sufficient for balancing and orientation projects. | Low cost and provides enough data for robot navigation.

4 × Weeemake Wheels Ø65 | Weeemake Robot Wheels / Rubber Wheels | Weeemake wheels are compatible with standard DC motors, lightweight, good surface grip. | Excellent traction + easy mounting without adapters.
LEGO Technic Pieces | 3D Printed Parts / Metal Frames | LEGO Technic is flexible, precise in dimensions, easy to assemble/disassemble, safe to use. | Much faster and simpler to prototype and modify compared to custom-made parts.

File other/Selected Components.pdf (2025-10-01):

ESP32-WROOM-32 Overview

ESP32-WROOM-32 is a microcontroller by Espressif with Wi-Fi and Bluetooth capabilities, widely used in IoT projects, robotics, and smart devices.

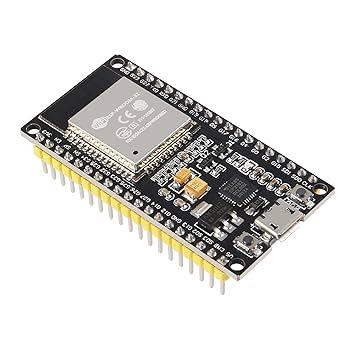
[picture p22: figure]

Key Specs

- Processor: Dual-core Xtensa® 32-bit LX6, up to 240 MHz
- Memory: 520 KB SRAM, 4 MB Flash
- Wireless: Wi-Fi 802.11 b/g/n, Bluetooth v4.2 (BR/EDR & BLE)
- GPIOs: ~34 programmable pins
- Interfaces: SPI, I2C, UART, PWM, I2S
- ADC/DAC: Analog input/output support

Features

- Dual connectivity (Wi-Fi + Bluetooth)
- Supports many protocols and peripherals
- Large community and ready-to-use libraries
- Programmable with Arduino IDE, MicroPython, ESP-IDF

Common Uses

- Robotics (smart/moving cars)
- Smart home systems
- Remote measurement and control devices
- IoT data collection and transmission

L298N (Motor Driver Module) Overview

The L298N is a dual H-bridge motor driver module that allows you to control the speed and direction of DC motors and stepper motors. It’s widely used in robotics and DIY electronics projects.

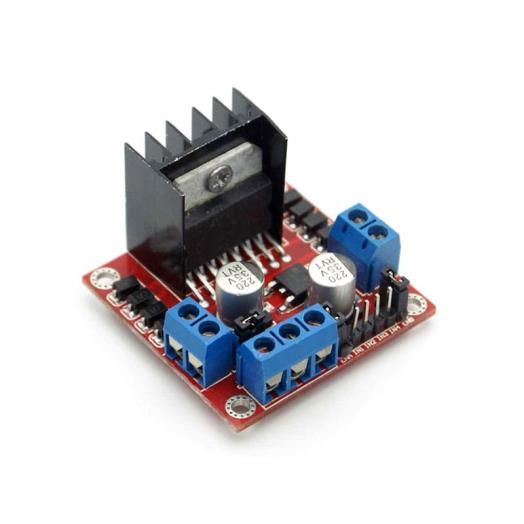
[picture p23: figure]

Key Specs

- Type: Dual H-Bridge
- Motor Voltage: 5V – 35V DC
- Current: Up to 2A per channel (continuous)
- Control:
- Direction: via IN1, IN2, IN3, IN4 pins
- Speed: via PWM (ENA, ENB pins)
- Supports: 2 DC motors or 1 stepper motor

Features

- Controls speed and rotation direction of motors
- Can drive two motors independently
- Built-in heat sink for protection
- Easy to interface with Arduino, ESP32, Raspberry Pi

Common Uses

- Robotics (car robots, moving platforms)
- Motorized projects (fans, pumps, conveyor belts)
- Stepper motor control in small CNC or 3D printers

- HC-SR04 Ultrasonic Sensor Overview
- The HC-SR04 is a popular ultrasonic distance sensor that measures the distance to objects by sending ultrasonic waves and calculating the time it takes for the echo to return. It’s cheap, simple, and widely used in robotics and obstacle detection.

•
- Key Specs

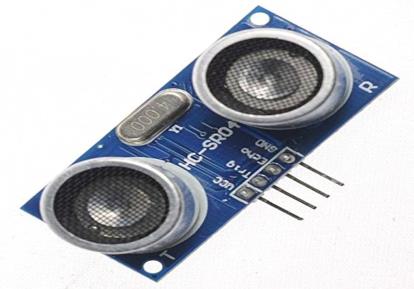
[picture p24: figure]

- Type: Ultrasonic distance sensor
- Operating Voltage: 5V DC
- Current: ~15 mA
- Range: 2 cm – 400 cm
- Accuracy: ±3 mm
- Interface Pins:
- VCC → Power (5V)
- GND → Ground
- TRIG → Trigger input
- ECHO → Echo output

•
- Features
- Simple 4-pin interface
- Measures distance using time of flight of sound waves
- Works well for obstacle avoidance in robots
- Low cost and widely available
- Common Uses
- Obstacle detection in robotic cars
- Distance measurement projects
- Parking assistance systems
- Level detection (water tanks, containers)

•

Pixy 2.1 (CMUcam5) Overview

The Pixy 2.1 is a smart vision sensor (camera) that can detect and track objects by color or shape. It’s widely used in robotics, automation, and computer vision projects.
Key Specs
- Type: Vision sensor / camera
- Resolution: 320×200 pixels
- Frame Rate: Up to 60 fps
- Interfaces: SPI, I²C, UART, USB
- Object Tracking: Can track multiple objects simultaneously
- Power Supply: 5V DC
- Special Feature: Built-in processor for real-time object recognition

Features

- Detects colored objects and lines
- Tracks multiple objects at the same time
- Sends coordinates directly to microcontrollers like Arduino or ESP32
- Can follow objects without heavy processing on the main board
- Compact and easy to integrate into robots

Common Uses

- Line-following robots
- Object detection and sorting robots
- Interactive projects (games, tracking, automation)
- Educational robotics and AI experiments

•
•
•

•
•
•
- Weeemake Wheel Overview
- The Weeemake Wheel is a robot wheel designed for small to medium-sized educational and DIY robots. It provides reliable traction and smooth movement on various surfaces.
•
- Key Specs

•
- Wheel Diameter: 65 mm
- Tire Type: Medium, rubber material
- Color: Black
- Weeemake Part Number: WW-065

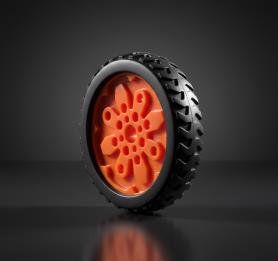
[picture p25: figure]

- Compatibility: Compatible with standard DC motors and robot chassis
•
- Features

•
- Provides good traction for educational robots – ensures stable movement on different surfaces.
- Fits standard motor shafts and robot hubs – easy integration into various robot designs.
- Durable rubber tire suitable for repeated use – long-lasting for multiple projects.
- Ideal for DIY robotics and STEM projects – perfect for educational and maker applications.
- Common Uses
- Wheels for Weeemake robots and small vehicles – suitable for robotics kits and mini vehicles.
- Educational robotics projects – ideal for STEM learning and classroom projects.
- DIY and maker robotics kits – great for hobbyists and custom robot builds.

•
•
•
•
•

- GM25 370 Motor Overview

•
- The GM25 370 is a DC geared motor commonly used in small robotics and DIY projects. It provides high torque at low speed, making it ideal for driving wheels or mechanical arms.

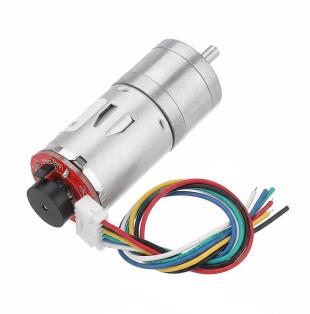
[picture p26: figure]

- Key Specs
- Type: DC Geared Motor
- Voltage: 6V DC
- No-load Speed: ~260 RPM
- Torque: Moderate, suitable for small robots
- Shaft Diameter: ~4 mm
- Mounting: Standard motor mounting holes for small chassis
- with hall encoder
- Features
- Compact and lightweight
- High torque output at low speed
- Reliable for robotic cars and small mechanical systems
- Can be paired with motor drivers like L298N

•
- Common Uses
- Driving wheels in small robots or cars
- DIY robotic arms or conveyor belts
- Educational projects requiring precise low-speed motion

•
•

•

•

•
- MG996R Servo Motor Overview
- The MG996R is a high-torque digital servo motor widely used in robotics, RC cars, and mechanical projects. It provides strong rotation force and reliable performance.
•
- Key Specs

•
- Type: Digital servo motor
- Operating Voltage: 4.8 – 7.2V DC
- Stall Torque: ~9.4 kg·cm (4.8V), ~11 kg·cm (6V)
- Speed: 0.17 sec/60° (4.8V), 0.14 sec/60° (6V)
- Rotation Angle: ~120° (standard), up to 180° modified
- Motor Type: Core motor with metal gears
- Dimensions: 40.7 × 19.7 × 42.9 mm
- Weight: ~55 g
•
- Features

•
- High torque suitable for heavy-duty applications
- Durable metal gear construction
- Stable and precise movement control
- Compatible with Arduino, Raspberry Pi, and robotics kits
- Common Uses
- Robotic arms and grippers
- Steering in RC cars
- Pan/tilt camera systems
- DIY robotics and automation projects

•
•
•

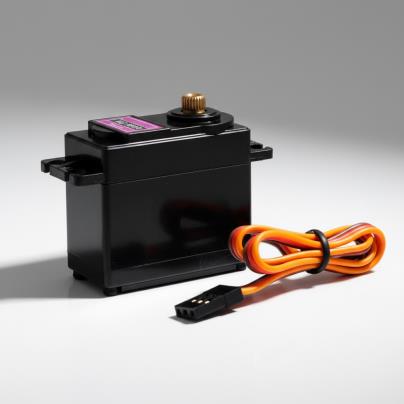
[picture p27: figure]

•
•

EV3 LEGO Technic Set Pieces Overview

The LEGO Technic EV3 pieces are modular building elements used to construct robots, vehicles, and mechanical structures. They form the structural framework for EV3 robots and allow integration of motors, sensors, and controllers.

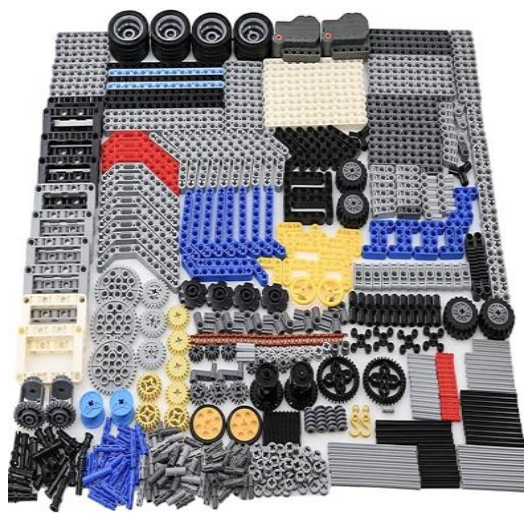
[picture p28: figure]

Key Components

- Beams & Liftarms: For building the robot’s frame and chassis
- Axles & Connectors: To connect beams and enable rotating parts
- Gears & Pulleys: For motion transfer and mechanical advantage
- Pins & Bushings: To securely attach parts together
- Special Parts: Mounts for motors, sensors, and wheels

Features

- Modular and reusable parts for multiple designs
- Compatible with EV3 motors, sensors, and controllers
- Supports mechanical movements (rotation, steering, lifts)
- Enables custom robotics and STEM projects

Common Uses

- Building LEGO EV3 robots and vehicles
- Creating mechanical linkages and robotic arms
- Educational projects in STEM and robotics learning
- Prototyping custom LEGO-based mechanisms

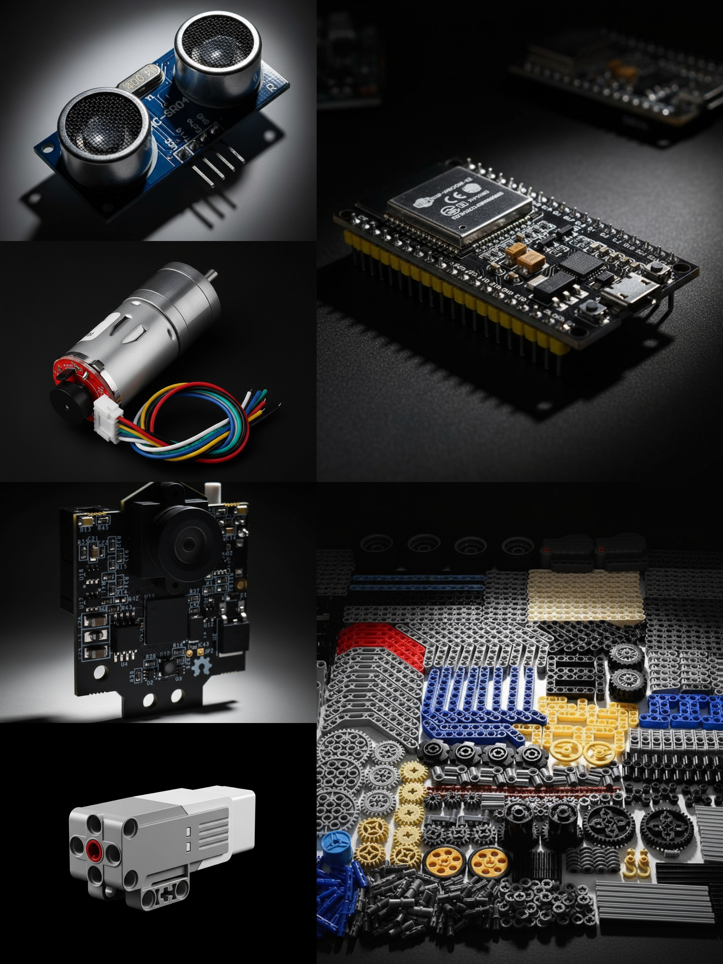
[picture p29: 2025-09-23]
v-photos/Robot parts/all.jpg

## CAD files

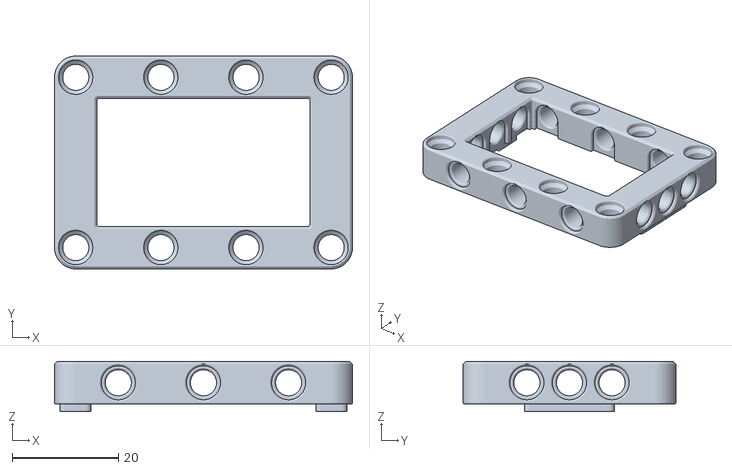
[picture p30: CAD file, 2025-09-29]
models/Servo to lego adapter.stl
56.0 x 40.0 x 9.40

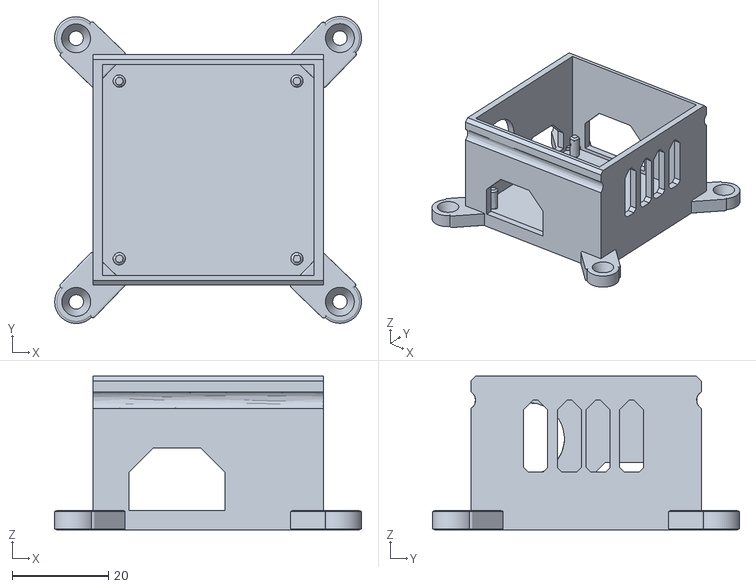
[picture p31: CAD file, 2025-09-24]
models/Motor Driver Case.stl
63.9 x 63.9 x 32.0

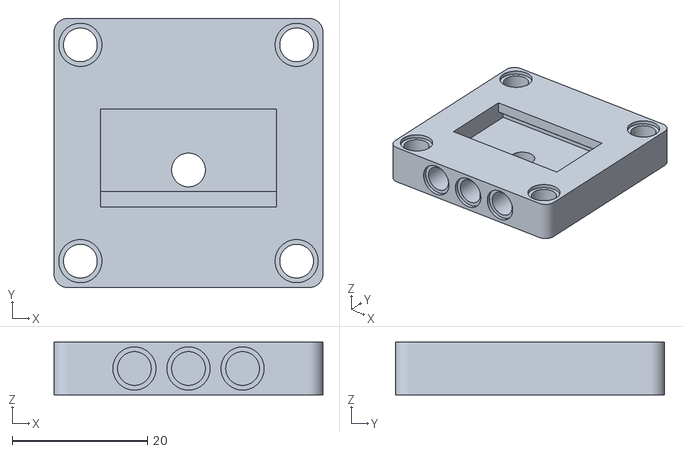
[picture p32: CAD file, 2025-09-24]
models/Gyroscope Holder.stl
39.8 x 39.8 x 7.80

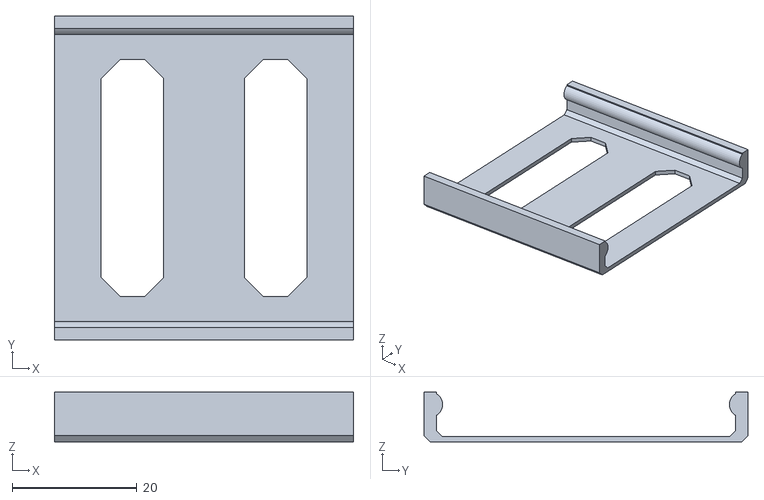
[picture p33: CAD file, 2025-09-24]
models/Motor Driver Case Cap.stl
48.0 x 52.0 x 8.00

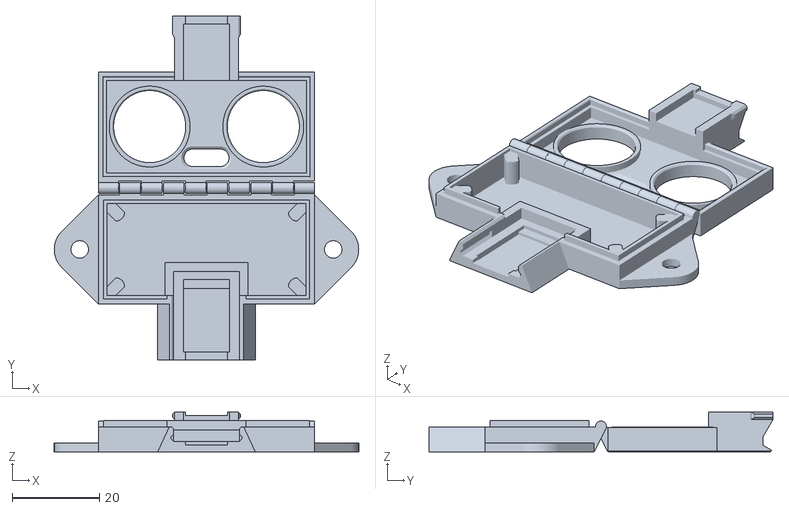
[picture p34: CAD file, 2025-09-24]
models/hc-sr04-ultrasonic-v11.stl
69.7 x 78.7 x 9.10

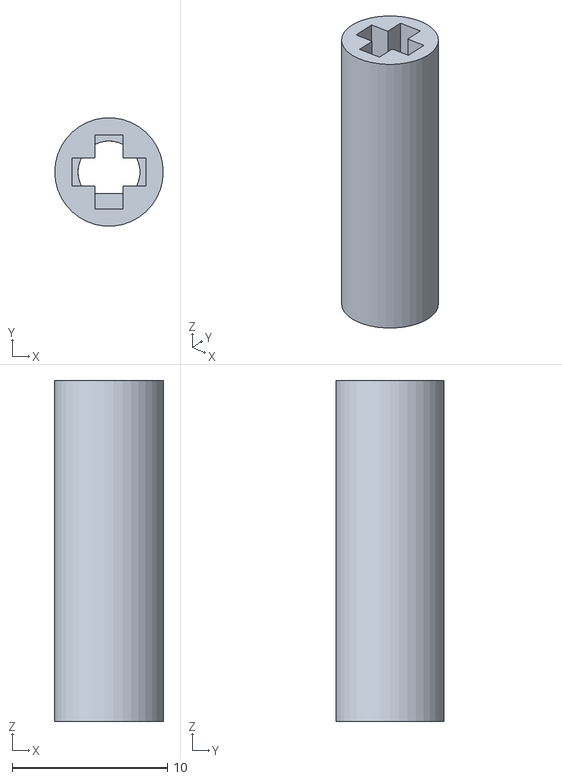
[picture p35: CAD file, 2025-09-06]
models/motor adapter for lego.stl
7.00 x 6.98 x 22.0

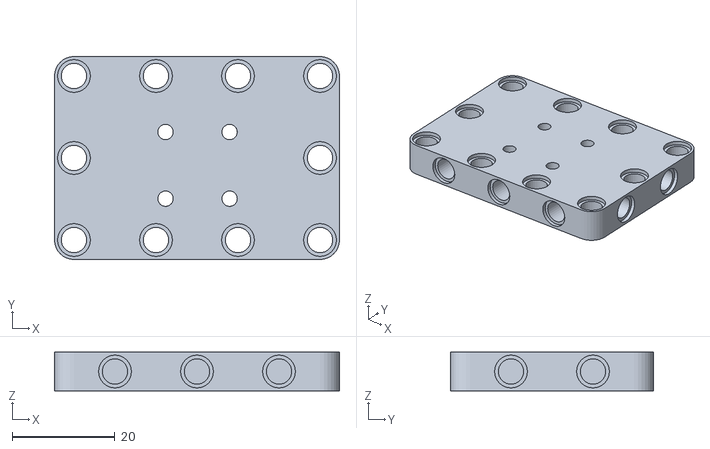
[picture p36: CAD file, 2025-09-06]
models/enhanced_holder.stl
55.6 x 39.6 x 7.60

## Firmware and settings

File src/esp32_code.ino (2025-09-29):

#include <ESP32Servo.h>
#include <Arduino.h>
#include <Wire.h>
#include <NewPing.h>
Servo myservo;
const int MPU_addr = 0x68;
float gyroX_bias = 0;
float gyroY_bias = 0;
float gyroZ_bias = 0;
float yaw = 0;
const int servoPin = 13; 

#define US_LEFT_TRIG 27
#define US_LEFT_ECHO 14
#define US_FRONT_TRIG 12
#define US_FRONT_ECHO 13
#define US_RIGHT_TRIG 2
#define US_RIGHT_ECHO 15

#define MOTOR1_IN1 17
#define MOTOR1_IN2 5
#define MOTOR1_ENA 16

NewPing sonar_left(US_LEFT_TRIG, US_LEFT_ECHO, MAX_DISTANCE);
NewPing sonar_front(US_FRONT_TRIG, US_FRONT_ECHO, MAX_DISTANCE);
NewPing sonar_right(US_RIGHT_TRIG, US_RIGHT_ECHO, MAX_DISTANCE);

float measured_distance_left = 0, measured_distance_front = 0,measured_distance_right=0;
int current_steering_angle = 0;
int target_steering_angle = 0;

const int MOTOR1_CHANNEL = 0;

#define MAX_STEERING_ANGLE 20

int16_t read16(int addr) {
  int16_t value;
  Wire.beginTransmission((uint8_t)MPU_addr);
  Wire.write((uint8_t)addr);
  Wire.endTransmission(false);
  Wire.requestFrom((uint16_t)MPU_addr, (uint8_t)2, (uint8_t)true);
  value = (Wire.read() << 8) | Wire.read();
  return value;
}

void calibrateGyro(int samples = 200) {
  long sumX = 0, sumY = 0, sumZ = 0;
  for (int i = 0; i < samples; i++) {
    int16_t gx = read16(0x43);
    int16_t gy = read16(0x45);
    int16_t gz = read16(0x47);
    sumX += gx; sumY += gy; sumZ += gz;
    delay(5);
  }
  gyroX_bias = sumX / (float)samples;
  gyroY_bias = sumY / (float)samples;
  gyroZ_bias = sumZ / (float)samples;
  Serial.println("Calibration done!");
  Serial.print("Bias Z (Yaw): "); Serial.println(gyroZ_bias);
}

void resetGyro() {
  yaw = 0;
  prevTime = millis();
}

void setupMPU() {
  Wire.begin();
  Wire.beginTransmission(MPU_addr);
  Wire.write(0x6B);
  Wire.write(0);
  Wire.endTransmission(true);
}

float getYaw() {
  unsigned long currentTime = millis();
  float dt = (currentTime - prevTime) / 1000.0;
  prevTime = currentTime;

  int16_t gz_raw = read16(0x47);
  float gz = gz_raw - gyroZ_bias;
  float gz_dps = gz / 131.0;

  yaw += gz_dps * dt;
  if (yaw > 180) yaw -= 360;
  if (yaw < -180) yaw += 360;

  return yaw;
}



void set_drive_motor(int speed) {
  speed = constrain(speed, -255, 255);
  if (speed >= 0) {
    digitalWrite(MOTOR1_IN1, HIGH);
    digitalWrite(MOTOR1_IN2, LOW);
  } else {
    digitalWrite(MOTOR1_IN1, LOW);
    digitalWrite(MOTOR1_IN2, HIGH);
  }
  ledcWrite(MOTOR1_CHANNEL, abs(speed));
}
// Define the min and max pulse widths for the DS558HV servo
// These values might need calibration for optimal performance
// Standard values are 500us to 2500us for 180 degrees.
// For a 40 degree servo, we need to find the pulse width for -20, 0, and +20 degrees.
// Let\'s assume a linear mapping for now. If 1500us is 0 degrees, and the total travel is 40 degrees,
// then 20 degrees corresponds to a certain pulse width change.
// A common mapping for 180 degrees is 500us to 2500us (2000us range).
// For 40 degrees, the range would be (40.0/180.0) * 2000.0 = 444.44us. (Using floats for precision)
// So, if 0 degrees is 1500us, then -20 degrees would be 1500 - (444.44/2) = 1500 - 222.22 = 1277.78us.
// And +20 degrees would be 1500 + (444.44/2) = 1500 + 222.22 = 1722.22us.
// Let\'s use these calculated values as a starting point, rounded to integers.


const int center = 1500; // Pulse width for 0 degrees (approx)

void setup() {
  Serial.begin(115200);
  myservo.setPeriodHertz(50); // Standard 50Hz servo
  myservo.attach(servoPin, MIN_PULSE_WIDTH, MAX_PULSE_WIDTH);
  Serial.println("Servo initialized. Moving to 0 degrees.");
  setAngle(0); // Move to initial 0 degree position
}

float get_filtered_distance(NewPing &sensor) {
  float sum = 0;
  byte valid = 0;
  for (byte i = 0; i <5; i++) {
    delay(5);
    float dist = sensor.ping_cm();
    if (dist > 0 && dist < MAX_DISTANCE) {
      sum += dist;
      valid++;
    }
  }
  return valid > 0 ? sum / valid : 0;
}

void setAngle(int angle) {
  long pulseWidth = map(angle, -MAX_STEERING_ANGLE, MAX_STEERING_ANGLE, center+(MAX_STEERING_ANGLE/180)*2000), center-(MAX_STEERING_ANGLE/180)*2000));
  myservo.writeMicroseconds(pulseWidth);
  Serial.print("Setting servo to angle: ");
  Serial.print(angle);
  Serial.print(" degrees (pulse width: ");
  Serial.print(pulseWidth);
  Serial.println(" us)");
}
//--------------------------------------------------------------
// --- PID parameters (tune them!) ---
float Kp_dist = 2.0, Kd_dist = 0.5;
float Kp_gyro = 3.0, Kd_gyro = 0.8;

float integral_dist = 0, prev_error_dist = 0;
float integral_gyro = 0, prev_error_gyro = 0;

int distance_output = 0;
bool use_distance_pid = true;

// --- Targets ---
const float target_yaw = 0.0; // straight direction

// --- PID for left/right balance ---
void pid_distance_balance() {
  float left = get_filtered_distance(sonar_left);
  float right = get_filtered_distance(sonar_right);

  // Error: want left == right
  float error = left - right;

  float derivative = error - prev_error_dist;
  prev_error_dist = error;

  float output = (Kp_dist * error) + (Kd_dist * derivative);

  // Clamp steering to max
  output = constrain(output, -MAX_STEERING_ANGLE, MAX_STEERING_ANGLE);
  distance_output = output;

  // Apply steering correction
  setAngle((int)output);

  Serial.print("Left: "); Serial.print(left);
  Serial.print("  Right: "); Serial.print(right);
  Serial.print("  Error: "); Serial.print(error);
  Serial.print("  Output: "); Serial.println(output);

  // If angle exceeds 30°, switch to gyro PID
  if (output >= 30) {
    output=25;
  }
  else if(output<=-30){
    output=-25;
  }
  if(abs(getYaw())>30){
    use_distance_pid = false;
    integral_gyro = 0;
    prev_error_gyro = 0;
    Serial.println(">>> Switching to Gyro PID");
  }
}

// --- PID for gyro stabilization ---
void pid_gyro() {
  float current_yaw = getYaw();
  float error = target_yaw - current_yaw;

  float derivative = error - prev_error_gyro;
  prev_error_gyro = error;

  float output = (Kp_gyro * error) + (Kd_gyro * derivative);
  output = constrain(output, -MAX_STEERING_ANGLE, MAX_STEERING_ANGLE);

  setAngle((int)output);

  Serial.print("Yaw: "); Serial.print(current_yaw);
  Serial.print("  Gyro PID Output: "); Serial.println(output);

  // When robot is straight again, switch back to distance PID
  if(output>=30){
    output=25;
  }
  else if(output<=-30){
    output=-25
  }
  if (abs(current_yaw) < 2.0) {
    use_distance_pid = true;
    integral_dist = 0;
    prev_error_dist = 0;
    Serial.println(">>> Switching back to Distance PID");
  }
}

String dirc(){
  float left = get_filtered_distance(sonar_left);
  float right = get_filtered_distance(sonar_right);
  float front = get_filtered_distance(sonar_front);
  if(front<50){
    if(right>100){
      return "right";
    }
    else return "left";
  }
  else{
    return "forward";
  }
}

void turn_90Deg(int deg){
  while (getYaw()<85){
    setAngle(deg);
  }
  stop_robot();
  setAngle(0);
  resetGyro(0);
  curr+=90;
}
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

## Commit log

2025-09-01 updating models prototypes
    [motor gear.stl, motor holder.stl]
2025-09-06 uploading models
    [enhanced_holder.stl, motor adapter for lego.stl]
2025-09-11 deleting some unimportant models
    [motor gear.stl, motor holder.stl]
2025-09-11 Create تعريف (2).pdf
